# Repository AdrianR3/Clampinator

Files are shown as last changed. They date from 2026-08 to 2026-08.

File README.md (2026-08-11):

# The Clampinator

Inspired by the [ODrive Regen Clamp](https://shop.odriverobotics.com/products/odrive-regeneration-clamp), the clampinator is a custom built regeneration clamp targeting 16-60V systems.

PCB-front-red

## Key Features
 - 16-60V input
 - Adjustable clamp voltage via trimpot
 - Full reverse current protection via TI's [LM7481-Q1](https://www.ti.com/product/LM7481-Q1)
   - Ideal diode inrush current limiting supported, but marked as DNP
 - External pre-charge resistor
 - **FULL galvanic isolation between power and logic domains**
 - USB-C port for programming
 - STM32H5 based logic control
   - Digital control to disconnect power input from output
   - 2x CAN FD exposed w/toggleable termination resistors
 - Two onboard LEDs (Yellow and RGB)
 - Two 10k thermistor slots for thermistors
 - Two 15V outputs for active cooling fans

> [!CAUTION]
> The Clampinator must not be plugged in unless the power switch is off. To turn on, slide power switch to `PRECHARGE`, and only proceed to `RUN` after allowing at least 1s for the bulk capacitors to charge.

## Using the CAN bus

The STM32 on the board is equipped with two built in CAN FD controllers, and the Clampinator has two accompanying CAN transcievers in the bottom left of the board. There is dip switch `SW5` which can be used to toggle the internal 120Ω termination resistors.

## Building the Clampinator
The Clampinator can be ordered from sites like JLCPCB. The KiCAD source files are in `./KiCAD` and the production gerber files are in `./KiCAD/prod` along with the bom.

## Images 

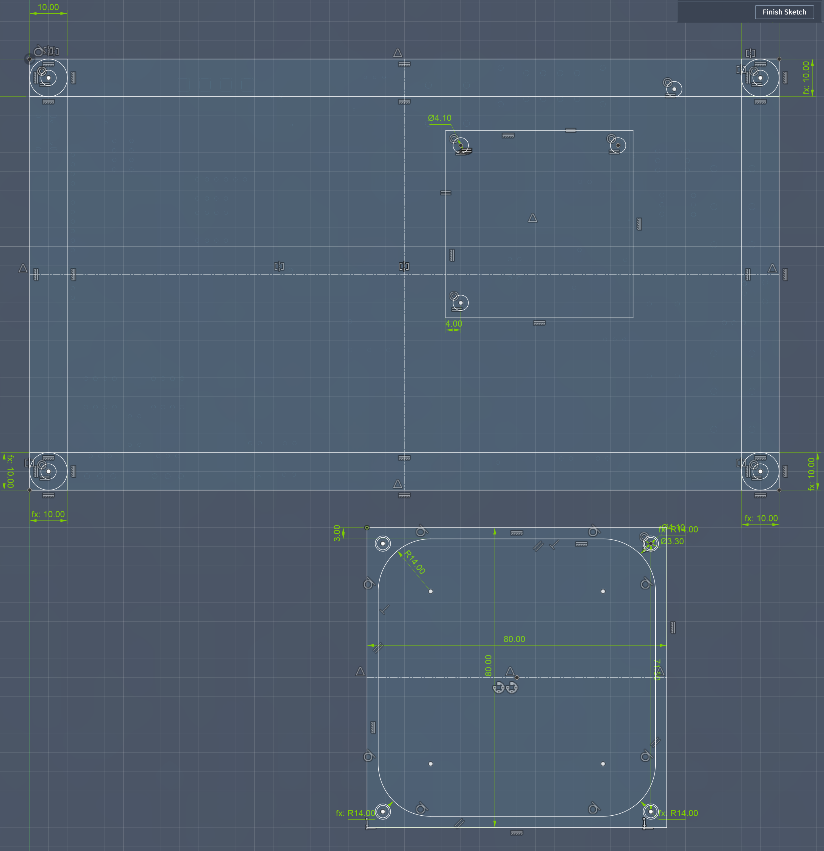
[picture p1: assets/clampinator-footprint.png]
Clampinator Base and Fan Footprint
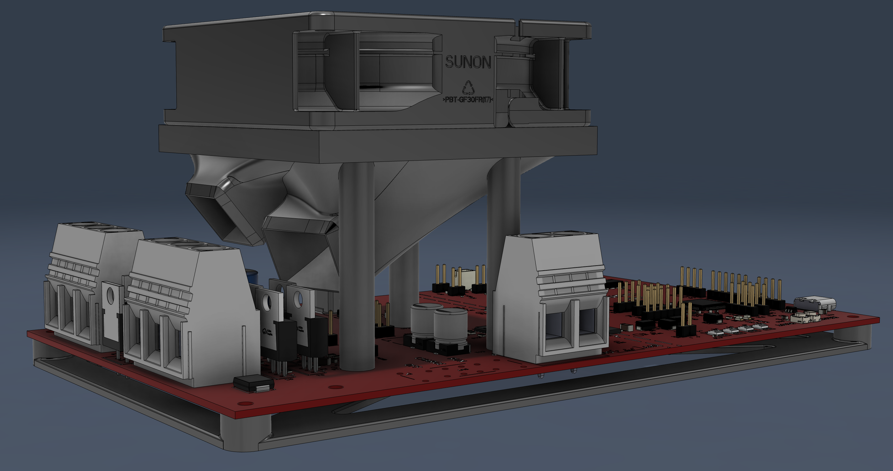
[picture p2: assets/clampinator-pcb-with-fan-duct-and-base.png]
Clampinator 3D Render with Fan and Duct
  
 
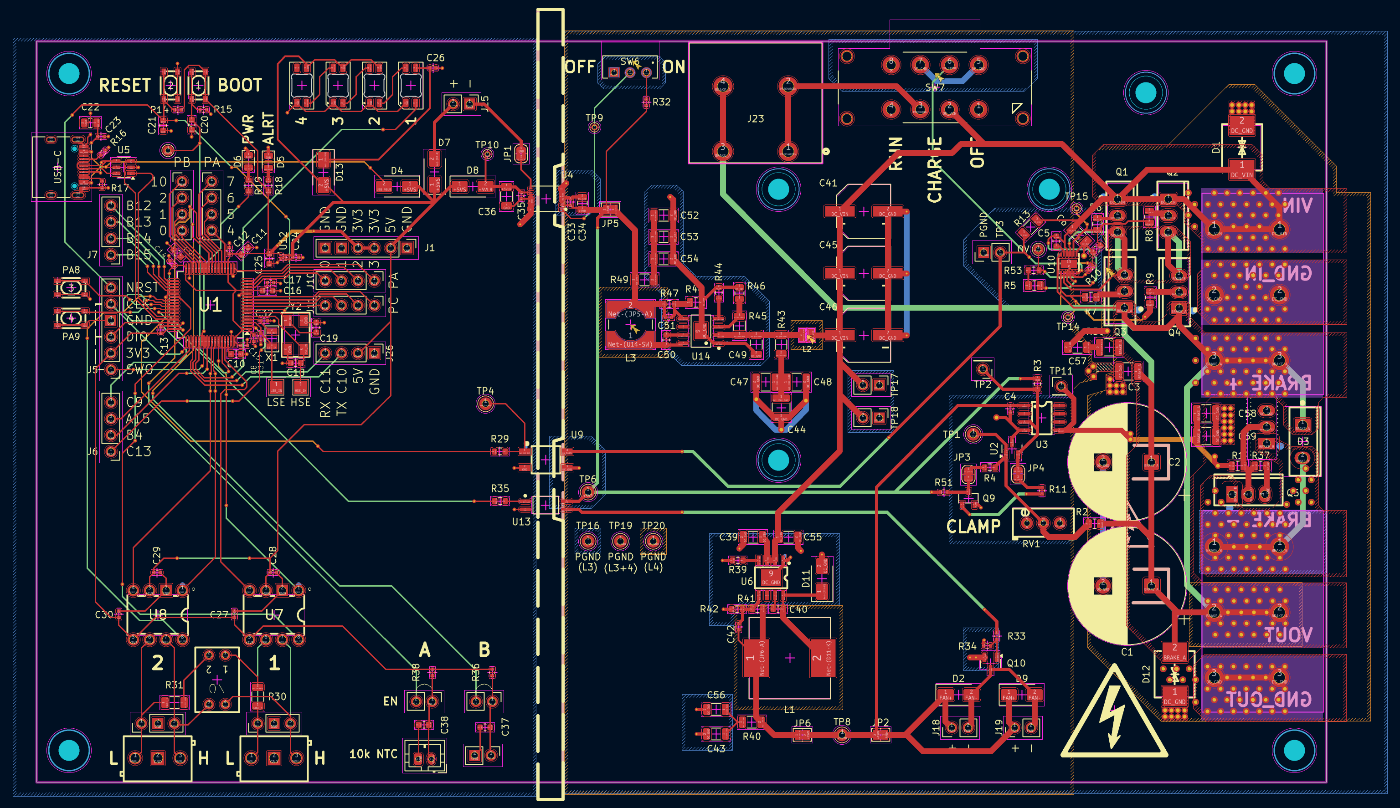
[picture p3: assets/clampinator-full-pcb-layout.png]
Clampinator Full PCB Layout
 

## Schematic

### Main Circuit
Main Circuit (Page 1 of 3)

## Logic Side Circuit
(Page 2 of 3)

## Thermal Management
(Page 3 of 3)

## BOM

| **Name** | **Purpose** | **Quantity** | **Total Cost (USD)** | **Link** | **Distributor** |
|---|---|---|---|---|---|
| LCSC Parts | Majority of PCB Components (With GSDL selected) | | 124.28 | | LCSC |
| 150R 25W Resistor | Precharge Resistor (Inrush Current Limiting) | 1 | 5.19 | https://www.digikey.com/en/products/detail/riedon-products-by-bourns/UAL25-150RF8/3886469 | DigiKey |
| 1818-VP036584000AG-ND | Connect Main Power | 2 | 5.50 | https://www.digikey.com/en/products/detail/amphenol-anytek/VP036584000AG/10378245 | DigiKey |
| 1818-VP0265840000G-ND | Connect Precharge Resistor | 1 | 3.10 | https://www.digikey.com/en/products/detail/amphenol-anytek/VP0265840000G/10378270 | DigiKey |
| EG1847-ND | Switch for Logic Side of Board | | 0.89 | https://www.digikey.com/en/products/detail/e-switch/EG1270/6076 | DigiKey |
| 259-1805-ND | Active Cooling Fan (price includes est. tariff) | 2 | 15.48 | https://www.digikey.com/en/products/detail/sunon-fans/MF80252V1-1000U-A99/6198743 | DigiKey |
| SW115-ND | (GPI-154-3013) Precharge Switch | | 1.83 | https://www.digikey.com/en/products/detail/cw-industries/GPI-154-3013/902 | DigiKey |
| 1.6R 500W Resistor | Main brake resistor | | 29.99 | https://www.youdaelectronics.com/products/1pc-500w-watt-16-ohm-500w-16r-aluminum-housing-wire-wound-resistor-29x52x250mm-3199 | Youda Electronics |
| JLCPCB + Stencil | Main Clampinator Board | 1 | 101.38 | | JLCPCB |

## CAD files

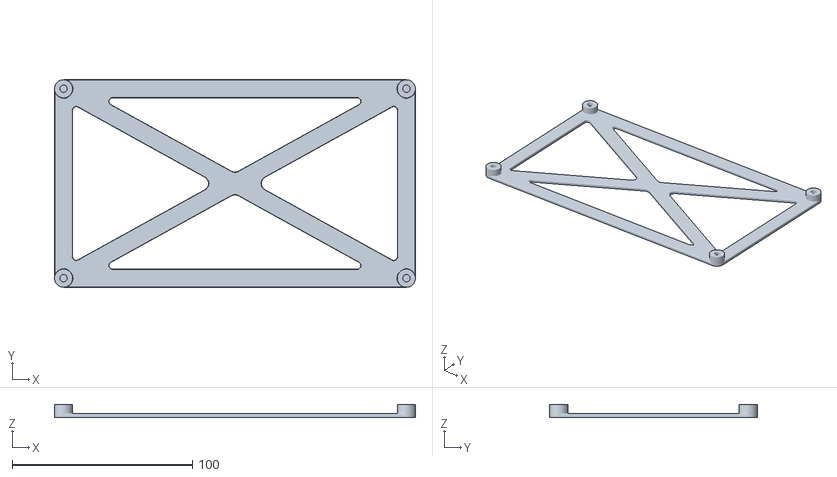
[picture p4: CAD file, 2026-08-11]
3dCAD/v1/Clampinator-base.stl
200.1 x 115.0 x 7.00

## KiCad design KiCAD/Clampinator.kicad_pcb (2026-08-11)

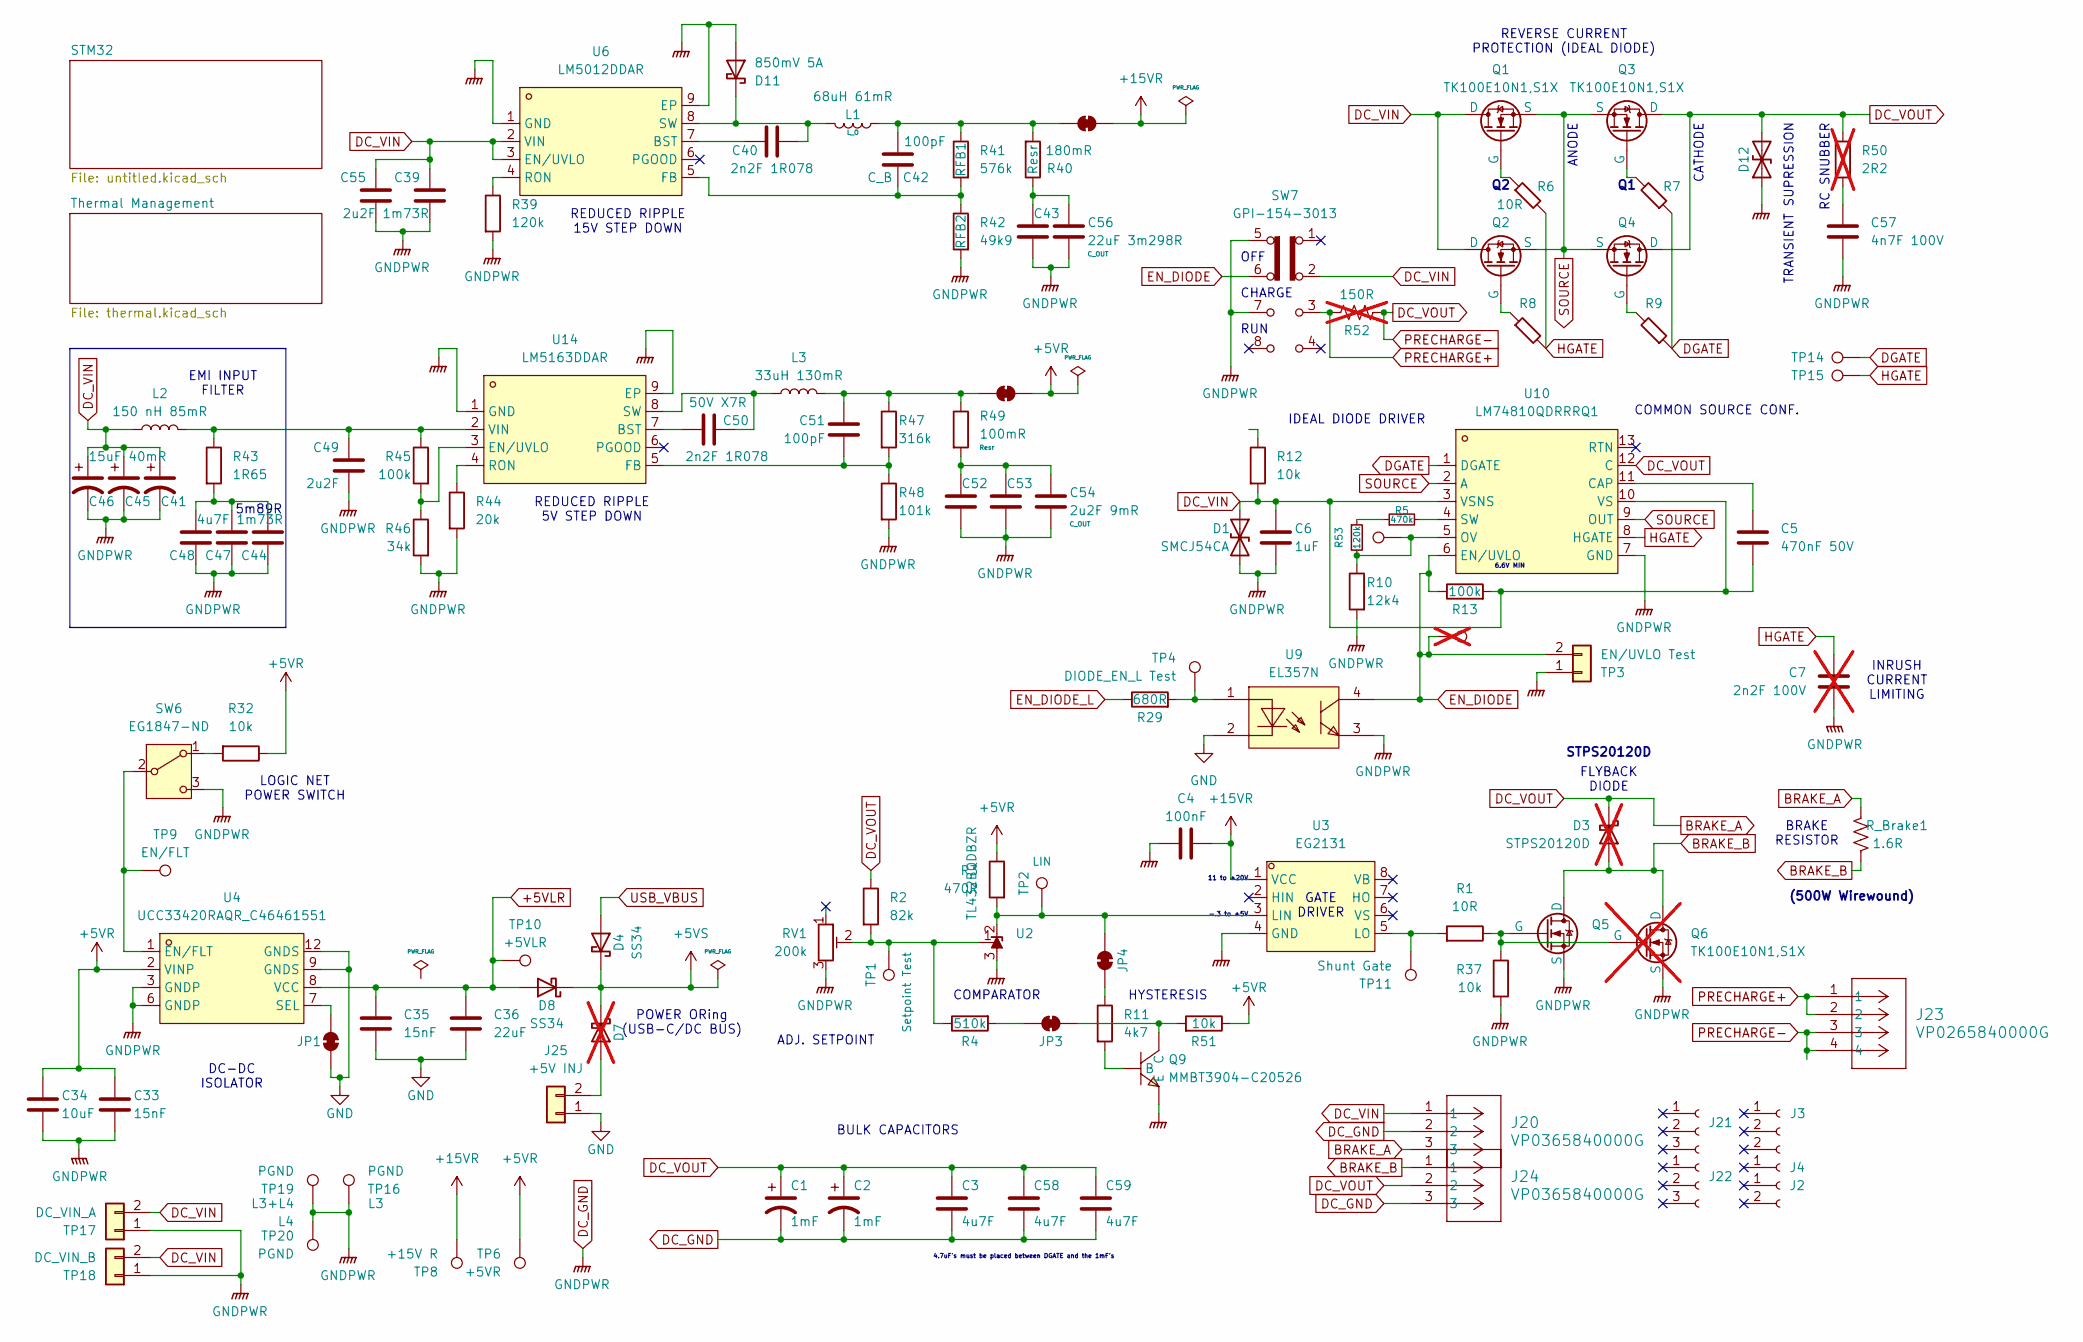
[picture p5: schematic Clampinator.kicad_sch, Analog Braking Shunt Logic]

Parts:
C1, C2: 1mF; CP_Radial_D18.0mm_P7.50mm; MPN ECA2AM102; LCSC Part C178408
C3, C58, C59: 4u7F; C_1210_3225Metric; LCSC Part C915836
C4: 100nF; C_0402_1005Metric; LCSC Part C307331
C5: 470nF 50V; C_0603_1608Metric; LCSC Part C1620
C6: 1uF; C_1206_3216Metric; LCSC Part C13832
C7: 2n2F 100V; C_0603_1608Metric; not fitted
C33, C35: 15nF; C_0402_1005Metric; LCSC Part C1548
C34: 10uF; C_0805_2012Metric; LCSC Part C15850
C36: 22uF; C_1206_3216Metric; LCSC Part C12891
C39, C55: 2u2F 1m73R; C_1206_3216Metric; LCSC Part C5122251
C40, C50: 2n2F 1R078; C_0603_1608Metric; LCSC Part C1604
C41, C45, C46: 15uF 40mR; CAP-SMD_BD8.0-L8.3-W8.3-LS9.3-FD; MPN 100SXV15M; LCSC Part C542593
C42, C51: 100pF; C_0402_1005Metric; LCSC Part C1546
C43, C56: 22uF 3m298R; C_1206_3216Metric; LCSC Part C12891
C44, C47, C48: 4u7F 1m73R; C_1210_3225Metric; LCSC Part C915836
C49: 2u2F; C_1206_3216Metric; LCSC Part C5122251
C52, C53, C54: 2u2F 9mR; C_1206_3216Metric; LCSC Part C5122251
C57: 4n7F 100V; C_1206_3216Metric; LCSC Part C393168
D1: SMCJ54CA; SMC_L6.9-W5.9-LS7.9-BI; MPN SMCJ54CA-13-F; LCSC Part C135179
D3: STPS20120D; TO-220AC_L10.0-W4.5-P5.08-T; MPN STPS20120D; LCSC Part C10623; not fitted
D4, D8: SS34; D_SMA; LCSC Part C8678
D7: SS34; D_SMA; LCSC Part C8678; not fitted
D11: 850mV 5A; D_SMA; LCSC Part C65010
D12: SMCJ64CA; SMC_L6.9-W5.9-LS7.9-BI; MPN SMCJ64CA/TR13; LCSC Part C123977
J2, J3, J4: Conn_01x02_Socket; PinHeader_1x02_P2.54mm_Vertical
J20, J24: VP0365840000G; VP0265840000G_THT; DigiKey BOM YES
J21, J22: Conn_01x03_Socket
J23: VP0265840000G; CONN04_VP026584_20P32X18P3_AMP; DigiKey BOM YES
J25: +5V INJ; PinHeader_1x02_P2.54mm_Vertical
JP1: SolderJumper_2_Bridged; SolderJumper-2_P1.3mm_Bridged2Bar_RoundedPad1.0x1.5mm
JP3, JP4: SolderJumper_2_Bridged; SolderJumper-2_P1.3mm_Bridged_RoundedPad1.0x1.5mm
JP5: SolderJumper_2_Bridged; SolderJumper-2_P1.3mm_Bridged2Bar_Pad1.0x1.5mm
JP6: +15VR; SolderJumper-2_P1.3mm_Bridged2Bar_Pad1.0x1.5mm
L1: 68uH 61mR; IND-SMD_L12.5-W12.5; MPN CYH125-68UH; LCSC Part C7431083
L2: 150 nH 85mR; WE-MAPI_2010; MPN 744383430033; LCSC Part C6069597
L3: 33uH 130mR; IND_SRR6038-330Y; MPN SRR6038-330Y; LCSC Part C2041395
Q1, Q2, Q3, Q4, Q5: TK100E10N1,S1X; TO-220-3_L10.0-W4.5-P2.54-L; MPN TK100E10N1,S1X; LCSC Part C5986394
Q6: TK100E10N1,S1X; TO-220-3_L10.0-W4.5-P2.54-L; MPN TK100E10N1,S1X; LCSC Part C5986394; not fitted
Q9: MMBT3904-C20526; SOT-23-3_L2.9-W1.3-P1.90-LS2.4-BR; MPN MMBT3904(RANGE:100-300); LCSC Part C20526
R1, R6, R7, R8, R9: 10R; R_0805_2012Metric; LCSC Part C17415
R2: 82k; R_0805_2012Metric; LCSC Part C2849357
R3: 470R; R_0603_1608Metric; LCSC Part C23179
R4: 510k; R_0603_1608Metric; LCSC Part C23192
R5: 470k; R_0805_2012Metric; LCSC Part C17709
R10: 12k4; R_0402_1005Metric; LCSC Part C25752
R11: 4k7; R_0402_1005Metric; LCSC Part C25900
R12: 10k; R_1206_3216Metric; LCSC Part C17902
R13, R45: 100k; R_1206_3216Metric; LCSC Part C17900
R29: 680R; R_0603_1608Metric; LCSC Part C23228
R32, R51: 10k; R_0402_1005Metric; LCSC Part C25744
R37: 10k; R_0805_2012Metric; LCSC Part C17414
R39, R53: 120k; R_0603_1608Metric; LCSC Part C25808
R40: 180mR; R_1206_3216Metric; LCSC Part C24436
R41: 576k; R_0603_1608Metric; LCSC Part C245981
R42: 49k9; R_0603_1608Metric; LCSC Part C23184
R43: 1R65; R_1206_3216Metric; LCSC Part C79297
R44: 20k; R_0603_1608Metric; LCSC Part C4184
R46: 34k; R_0805_2012Metric; LCSC Part C2077219
R47: 316k; R_0603_1608Metric; LCSC Part C185340
R48: 101k; R_0805_2012Metric; LCSC Part C7302896
R49: 100mR; R_1206_3216Metric; LCSC Part C25334
R50: 2R2; R_1210_3225Metric; MPN ERJ-P08J2R2V; not fitted
R52: 150R; SolderWire-4sqmm_1x02_P12mm_D3mm_OD6mm; MPN UAL25-150RF8; DigiKey BOM YES; not fitted
RV1: 200k; RES-ADJ-TH_3P-L9.5-W4.9-P2.50-L_3296W; MPN 3296W-1-204LF; LCSC Part C49190460
R_Brake1: 1.6R
SW6: EG1847-ND; SW_EG1270; DigiKey BOM YES
SW7: GPI-154-3013; SW_Slide_GPL-154-3013_DP3T_Angled; DigiKey BOM YES
TP1: Setpoint Test; TestPoint_THTPad_D2.0mm_Drill1.0mm
TP2: LIN; PinHeader_1x01_P2.54mm_Vertical
TP3: EN/UVLO Test; PinHeader_1x02_P2.54mm_Vertical
TP4: DIODE_EN_L Test; TestPoint_THTPad_D2.0mm_Drill1.0mm
TP6: +5VR; TestPoint_THTPad_D2.0mm_Drill1.0mm
TP8: +15V R; TestPoint_THTPad_D2.0mm_Drill1.0mm
TP9: EN/FLT; TestPoint_THTPad_D1.0mm_Drill0.5mm
TP10: +5VLR; TestPoint_THTPad_D1.0mm_Drill0.5mm
TP11: Shunt Gate; PinHeader_1x01_P2.54mm_Vertical
TP13: TestPoint; TestPoint_THTPad_D1.5mm_Drill0.7mm
TP14: D; TestPoint_THTPad_D1.0mm_Drill0.5mm
TP15: H; TestPoint_THTPad_D1.0mm_Drill0.5mm
TP16, TP19, TP20: PGND; TestPoint_THTPad_D2.0mm_Drill1.0mm
TP17: DC_VIN_A; PinHeader_1x02_P2.54mm_Vertical
TP18: DC_VIN_B; PinHeader_1x02_P2.54mm_Vertical
TP-not3: EN/UVLO Test; TestPoint_THTPad_D2.0mm_Drill1.0mm; not fitted
U2: TL432BQDBZR; SOT-23; LCSC Part C53724
U3: EG2131; SOIC-8_L5.0-W4.0-P1.27-LS6.0-BL; MPN EG2131; LCSC Part C193777
U4: UCC33420RAQR_C46461551; VSON-12_L5.0-W4.0-P0.65-TL_PUCC33420QRAQRQ1; MPN UCC33420RAQR; LCSC Part C46461551
U6: LM5012DDAR; SOPOWERPAD-8_L4.9-W3.9-P1.27-LS6.0-BL-EP; MPN LM5012DDAR; LCSC Part C6079494
U9: EL357N; OPTO-SMD-4_L4.4-W4.1-P2.54-LS7.0-TL; MPN EL357N(A)(TA)-G; LCSC Part C42385000
U10: LM74810QDRRRQ1; WSON-12_L3.0-W3.0-P0.50-TL-EP-2; MPN LM74810QDRRRQ1; LCSC Part C3215601
U14: LM5163DDAR; ESOP-8_L4.9-W3.9-P1.27-LS6.0-BL-EP2.6; MPN LM5163DDAR; LCSC Part C2873264

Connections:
+5VLR: C35.1, C36.1, D8.2 (A), TP10.1 (1_1), U4.8 (VCC)
+5VR: C33.1, C34.1, JP5.2 (B), R3.1, R32.1, R51.1, TP6.1 (1_1), U4.2 (VINP); also elsewhere on the board
+5VS: D4.1 (K), D7.1 (K), D8.1 (K); also elsewhere on the board
+15VR: C4.2, JP6.2 (B), TP8.1 (1_1), U3.1 (VCC); also elsewhere on the board
BRAKE_A: C1.1, C2.1, C3.1, C58.1, C59.1, D3.1 (K), D12.2 (A2), J20.3, J23.3, J23.4, J24.2, Q3.1 (D), Q4.1 (D), R2.1, R50.1, R52.2, R_Brake1.2, U10.12 (C)
BRAKE_B: D3.2 (A), J24.1, Q5.1 (D), Q6.1 (D), R_Brake1.1
DC_GND: C1.2, C2.2, C3.2, C4.1, C6.2, C7.2, C33.2, C34.2, C39.2, C41.2, C43.2, C44.2, C45.2, C46.2, C47.2, C48.2, C49.2, C52.2, C53.2, C54.2, C55.2, C56.2, C57.2, C58.2, C59.2, D1.2 (A2), D11.2 (A), D12.1 (A1), J20.2, J24.3, Q5.3 (S), Q6.3 (S), Q9.2 (E), R10.2, R37.2, R39.2, R42.2, R44.2, R46.2, R48.2, RV1.3, SW6.3 (C), SW7.5 (B), SW7.7 (C), TP3.1, TP16.1 (1_1), TP17.1, TP18.1, TP19.1 (1_1), TP20.1 (1_1), U2.3 (A), U3.4 (GND), U4.3 (GNDP), U4.6 (GNDP), U6.1 (GND), U6.9 (EP), U9.3 (EM), U10.7 (GND), U14.1 (GND), U14.9 (EP); also elsewhere on the board
DC_VIN: C5.2, C6.1, C39.1, C41.1, C45.1, C46.1, C55.1, D1.1 (A1), J20.1, L2.1, Q1.1 (D), Q2.1 (D), R12.2, R13.2, SW7.2 (B), TP17.2, TP18.2, U6.2 (VIN), U6.3 (EN/UVLO), U10.3 (VSNS), U10.10 (VS)
DGATE: R7.1, R9.1, TP14.1 (1_1), U10.1 (DGATE)
EN_DIODE: R13.1, SW7.6 (C), TP3.2, TP-not3.1, U9.4 (COL), U10.6 (EN/UVLO)
EN_DIODE_L: R29.1; also elsewhere on the board
GND: C35.2, C36.2, J25.1, JP1.1 (A), U4.9 (GNDS), U4.12 (GNDS), U9.2 (CA); also elsewhere on the board
HGATE: C7.1, R6.2, R8.2, TP15.1 (1_1), U10.8 (HGATE)
unnamed: C43.1, C56.1, R40.1
unnamed: C44.1, C47.1, C48.1, R43.2
unnamed: C52.1, C53.1, C54.1, R49.2
unnamed: C57.1, R50.2
unnamed: D7.2 (A), J25.2
unnamed: C40.2, D11.1 (K), L1.2, U6.8 (SW)
unnamed: JP1.2 (B), U4.7 (SEL)
unnamed: JP3.1 (A), R4.2
unnamed: JP3.2 (B), Q9.3 (C), R51.2
unnamed: JP4.1 (A), R3.2, TP2.1 (1_1), U2.2 (K), U3.3 (LIN)
unnamed: JP4.2 (B), R11.1
unnamed: C51.1, JP5.1 (A), L3.2, R47.1, R49.1
unnamed: C42.1, JP6.1 (A), L1.1, R40.2, R41.1
unnamed: Q1.2 (G), R6.1
unnamed: Q2.2 (G), R8.1
unnamed: Q3.2 (G), R7.2
unnamed: Q4.2 (G), R9.2
unnamed: Q5.2 (G), Q6.2 (G), R1.1, R37.1
unnamed: Q9.1 (B), R11.2
unnamed: R5.1, R53.1
unnamed: R32.2, SW6.1 (A)
unnamed: SW6.2 (B), TP9.1 (1_1), U4.1 (EN/FLT)
unnamed: R2.2, R4.1, RV1.2, TP1.1 (1_1), U2.1 (REF)
unnamed: R1.2, TP11.1 (1_1), U3.5 (LO)
unnamed: C40.1, U6.7 (BST)
unnamed: C42.2, R41.2, R42.1, U6.5 (FB)
unnamed: R39.1, U6.4 (RON)
unnamed: R29.2, TP4.1 (1_1), U9.1 (AN)
unnamed: C5.1, U10.11 (CAP)
unnamed: R10.1, R53.2, TP13.1 (1_1), U10.5 (OV)
unnamed: R5.2, U10.4 (SW)
unnamed: C50.2, U14.7 (BST)
unnamed: R45.2, R46.1, U14.3 (EN/UVLO)
unnamed: C51.2, R47.2, R48.1, U14.5 (FB)
unnamed: R44.1, U14.4 (RON)
unnamed: C50.1, L3.1, U14.8 (SW)
unnamed: C49.1, L2.2, R43.1, R45.1, U14.2 (VIN)
PRECHARGE+: J23.1, J23.2, R52.1, SW7.3 (C)
SOURCE: Q1.3 (S), Q2.3 (S), Q3.3 (S), Q4.3 (S), U10.2 (A), U10.9 (OUT)
USB_VBUS: D4.2 (A); also elsewhere on the board

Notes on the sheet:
ANODE
RC SNUBBER
HYSTERESIS
4.7uF's must be placed between DGATE and the 1mF's
COMMON SOURCE CONF.
GATE DRIVER
REVERSE CURRENT PROTECTION (IDEAL DIODE)
IDEAL DIODE DRIVER
DC-DC ISOLATOR
STPS20120D
FLYBACK DIODE
11 to +20V
CATHODE
CHARGE
6.6V MIN
EMI INPUT FILTER
RUN
LOGIC NET POWER SWITCH
-.3 to +5V
REDUCED RIPPLE 15V STEP DOWN
OFF
REDUCED RIPPLE 5V STEP DOWN
BULK CAPACITORS
(500W Wirewound)
BRAKE RESISTOR
COMPARATOR
INRUSH CURRENT LIMITING
TRANSIENT SUPRESSION
5m89R
ADJ. SETPOINT
POWER ORing (USB-C/DC BUS)

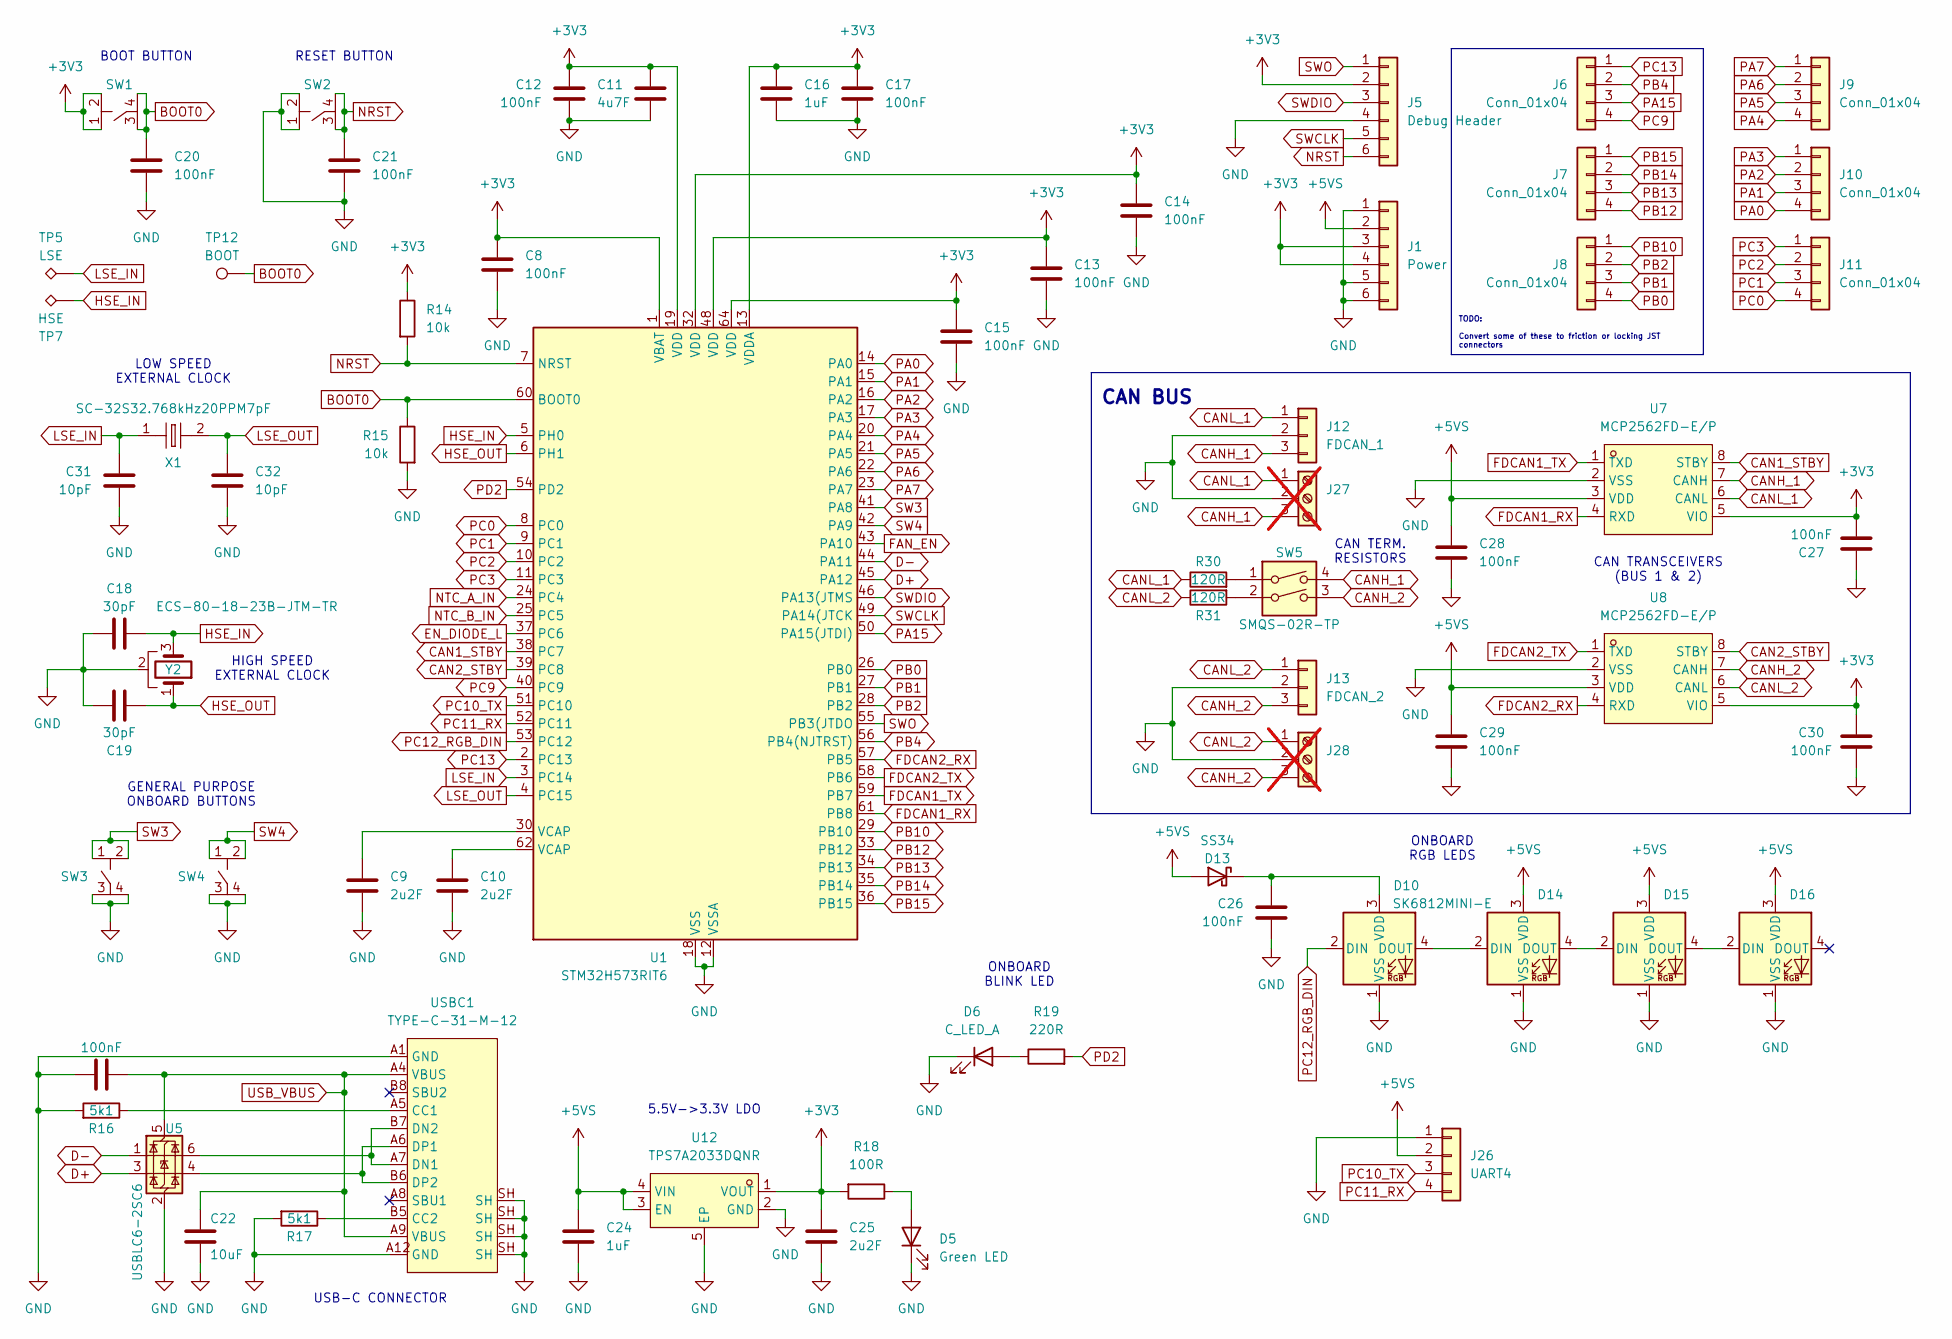
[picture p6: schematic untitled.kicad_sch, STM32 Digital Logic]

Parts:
C8, C12, C13, C14, C15, C17, C26, C27, C30: 100nF; C_0402_1005Metric; LCSC Part C1525
C9, C10, C25: 2u2F; C_0603_1608Metric; LCSC Part C23630
C11: 4u7F; C_0603_1608Metric; LCSC Part C19666
C16: 1uF; C_0603_1608Metric; LCSC Part C15849
C18, C19: 30pF; C_0603_1608Metric; LCSC Part C1658
C20, C21: 100nF; C_0603_1608Metric; LCSC Part C14663
C22: 10uF; C_0805_2012Metric; LCSC Part C440198
C23, C28, C29: 100nF; C_0402_1005Metric; LCSC Part C307331
C24: 1uF; C_0402_1005Metric; LCSC Part C52923
C31, C32: 10pF; C_0402_1005Metric; LCSC Part C32949
D5: Green LED; LED_0805_2012Metric; LCSC Part C2297
D6: C_LED_A; LED_0805_2012Metric; LCSC Part C2296
D10, D14, D15, D16: SK6812MINI-E; LED_SK6812MINI-E_3.2x2.8mm_P1.5mm
D13: SS34; D_SMA; LCSC Part C8678
J1: Power; PinHeader_1x06_P2.54mm_Vertical
J5: Debug Header; PinHeader_1x06_P2.54mm_Vertical
J6, J7, J8, J9, J10, J11: Conn_01x04; PinHeader_1x04_P2.54mm_Vertical
J12: FDCAN_1; PinHeader_1x03_P2.54mm_Vertical
J13: FDCAN_2; PinHeader_1x03_P2.54mm_Vertical
J26: UART4; PinHeader_1x04_P2.54mm_Vertical
J27, J28: Screw_Terminal_01x03; CONN-TH_3P-P3.50_OSTTE030161; not fitted
R14, R15: 10k; R_0402_1005Metric; LCSC Part C25744
R16, R17: 5k1; R_0402_1005Metric; LCSC Part C25905
R18: 100R; R_0603_1608Metric; LCSC Part C22775
R19: 220R; R_0603_1608Metric; LCSC Part C22962
R30, R31: 120R; R_1206_3216Metric; LCSC Part C17909
SW1, SW2, SW3, SW4: PTS810SJM250SMTRLFS; KEY-SMD_4P-L4.2-W3.2-P2.20-LS4.6; MPN PTS810SJM250SMTRLFS; LCSC Part C116501
SW5: SMQS-02R-TP; SW-TH_4P-L9.9-W6.8-P7.62-BL; MPN SMQS-02R-TP; LCSC Part C5299503
TP5: LSE; TestPoint_Pad_2.0x2.0mm
TP7: HSE; TestPoint_Pad_2.0x2.0mm
TP12: BOOT; TestPoint_THTPad_D1.5mm_Drill0.7mm
U1: STM32H573RIT6; LQFP-64_10x10mm_P0.5mm; LCSC Part C22371377
U5: USBLC6-2SC6; SOT-23-6; LCSC Part C7519
U7, U8: MCP2562FD-E/P; PDIP-8_L9.3-W6.4-P2.54-LS7.6-BL; MPN MCP2562FD-E/P; LCSC Part C640346
U12: TPS7A2033DQNR; UDFN-4_L1.0-W1.0-P0.65-TL; MPN TPS7A2033DQNR; LCSC Part C46459900
USBC1: TYPE-C-31-M-12; USB_C_Receptacle_HRO_TYPE-C-31-M-12; MPN TYPE-C-31-M-12; LCSC Part C165948
X1: SC-32S32.768kHz20PPM7pF; OSC-SMD_L3.2-W1.5; MPN SC-32S32.768kHz20PPM7pF; LCSC Part C97604
Y2: ECS-80-18-23B-JTM-TR; CRYSTAL-SMD_4P-L6.0-W3.5-BL; MPN ECS-80-18-23B-JTM-TR; LCSC Part C2450633

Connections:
+3V3: C8.1, C11.1, C12.1, C13.1, C14.1, C15.1, C16.1, C17.1, C25.1, C27.1, C30.1, J1.3, J1.4, J5.2, R14.1, R18.2, SW1.1, SW1.2, U1.1 (VBAT), U1.13 (VDDA), U1.19 (VDD), U1.32 (VDD), U1.48 (VDD), U1.64 (VDD), U7.5 (VIO), U8.5 (VIO), U12.1 (VOUT); also elsewhere on the board
+5VS: C24.1, C28.1, C29.2, D13.2 (A), D14.3 (VDD), D15.3 (VDD), D16.3 (VDD), J1.2, J26.2, U7.3 (VDD), U8.3 (VDD), U12.3 (EN), U12.4 (VIN); also elsewhere on the board
BOOT0: C20.1, R15.1, SW1.3, SW1.4, TP12.1 (1_1), U1.60 (BOOT0)
CAN1_STBY: U1.38 (PC7), U7.8 (STBY)
CAN2_STBY: U1.39 (PC8), U8.8 (STBY)
CANH_1: J12.3, J27.3, SW5.4, U7.7 (CANH)
CANH_2: J13.3, J28.3, SW5.3, U8.7 (CANH)
CANL_1: J12.1, J27.1, R30.1, U7.6 (CANL)
CANL_2: J13.1, J28.1, R31.1, U8.6 (CANL)
D+: U1.45 (PA12), U5.3 (I/O2)
D-: U1.44 (PA11), U5.1 (I/O1)
EN_DIODE_L: U1.37 (PC6); also elsewhere on the board
FAN_EN: U1.43 (PA10); also elsewhere on the board
FDCAN1_RX: U1.61 (PB8), U7.4 (RXD)
FDCAN1_TX: U1.59 (PB7), U7.1 (TXD)
FDCAN2_RX: U1.57 (PB5), U8.4 (RXD)
FDCAN2_TX: U1.58 (PB6), U8.1 (TXD)
GND: C8.2, C9.2, C10.2, C11.2, C12.2, C13.2, C14.2, C15.2, C16.2, C17.2, C18.1, C19.2, C20.2, C21.2, C22.2, C23.2, C24.2, C25.2, C26.2, C27.2, C28.2, C29.1, C30.2, C31.2, C32.2, D5.1 (K), D6.1 (K), D10.1 (VSS), D14.1 (VSS), D15.1 (VSS), D16.1 (VSS), J1.1, J1.5, J1.6, J5.4, J12.2, J13.2, J26.1, J27.2, J28.2, R15.2, R16.2, R17.2, SW2.1, SW2.2, SW3.3, SW3.4, SW4.3, SW4.4, U1.12 (VSSA), U1.18 (VSS), U1.31 (VSS), U1.47 (VSS), U1.63 (VSS), U5.2 (GND), U7.2 (VSS), U8.2 (VSS), U12.2 (GND), U12.5 (EP), USBC1.A1 (GND), USBC1.A12 (GND), USBC1.B1 (GND), USBC1.B12 (GND), USBC1.SH, Y2.2, Y2.4; also elsewhere on the board
HSE_IN: C18.2, TP7.1 (1_1), U1.5 (PH0), Y2.3
HSE_OUT: C19.1, U1.6 (PH1), Y2.1
LSE_IN: C31.1, TP5.1 (1_1), U1.3 (PC14), X1.1
LSE_OUT: C32.1, U1.4 (PC15), X1.2
NRST: C21.1, J5.6, R14.2, SW2.3, SW2.4, U1.7 (NRST)
NTC_A_IN: U1.24 (PC4); also elsewhere on the board
NTC_B_IN: U1.25 (PC5); also elsewhere on the board
unnamed: C9.1, U1.30 (VCAP)
unnamed: C10.1, U1.62 (VCAP)
unnamed: D5.2 (A), R18.1
unnamed: D6.2 (A), R19.1
unnamed: D10.4 (DOUT), D14.2 (DIN)
unnamed: C26.1, D10.3 (VDD), D13.1 (K)
unnamed: D14.4 (DOUT), D15.2 (DIN)
unnamed: D15.4 (DOUT), D16.2 (DIN)
unnamed: R30.2, SW5.1
unnamed: R31.2, SW5.2
unnamed: R16.1, USBC1.A5 (CC1)
unnamed: R17.1, USBC1.B5 (CC2)
unnamed: U5.6 (I/O1), USBC1.A7 (DN1), USBC1.B7 (DN2)
unnamed: U5.4 (I/O2), USBC1.A6 (DP1), USBC1.B6 (DP2)
PA0: J10.4, U1.14 (PA0)
PA1: J10.3, U1.15 (PA1)
PA2: J10.2, U1.16 (PA2)
PA3: J10.1, U1.17 (PA3)
PA4: J9.4, U1.20 (PA4)
PA5: J9.3, U1.21 (PA5)
PA6: J9.2, U1.22 (PA6)
PA7: J9.1, U1.23 (PA7)
PA15: J6.3, U1.50 (PA15(JTDI))
PB0: J8.4, U1.26 (PB0)
PB1: J8.3, U1.27 (PB1)
PB2: J8.2, U1.28 (PB2)
PB4: J6.2, U1.56 (PB4(NJTRST))
PB10: J8.1, U1.29 (PB10)
PB12: J7.4, U1.33 (PB12)
PB13: J7.3, U1.34 (PB13)
PB14: J7.2, U1.35 (PB14)
PB15: J7.1, U1.36 (PB15)
PC0: J11.4, U1.8 (PC0)
PC1: J11.3, U1.9 (PC1)
PC2: J11.2, U1.10 (PC2)
PC3: J11.1, U1.11 (PC3)
PC9: J6.4, U1.40 (PC9)
PC10_TX: J26.3, U1.51 (PC10)
PC11_RX: J26.4, U1.52 (PC11)
PC12_RGB_DIN: D10.2 (DIN), U1.53 (PC12)
PC13: J6.1, U1.2 (PC13)
PD2: R19.2, U1.54 (PD2)
SW3: SW3.1, SW3.2, U1.41 (PA8)
SW4: SW4.1, SW4.2, U1.42 (PA9)
SWCLK: J5.5, U1.49 (PA14(JTCK)
SWDIO: J5.3, U1.46 (PA13(JTMS)
SWO: J5.1, U1.55 (PB3(JTDO)
USB_VBUS: C22.1, C23.1, U5.5 (VBUS), USBC1.A4 (VBUS), USBC1.A9 (VBUS), USBC1.B4 (VBUS), USBC1.B9 (VBUS); also elsewhere on the board

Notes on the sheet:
CAN BUS
ONBOARD RGB LEDS
USB-C CONNECTOR
LOW SPEED EXTERNAL CLOCK
CAN TRANSCEIVERS (BUS 1 & 2)
HIGH SPEED EXTERNAL CLOCK
BOOT BUTTON
ONBOARD BLINK LED
CAN TERM. RESISTORS
RESET BUTTON
5.5V->3.3V LDO
GENERAL PURPOSE ONBOARD BUTTONS
TODO: Convert some of these to friction or locking JST connectors

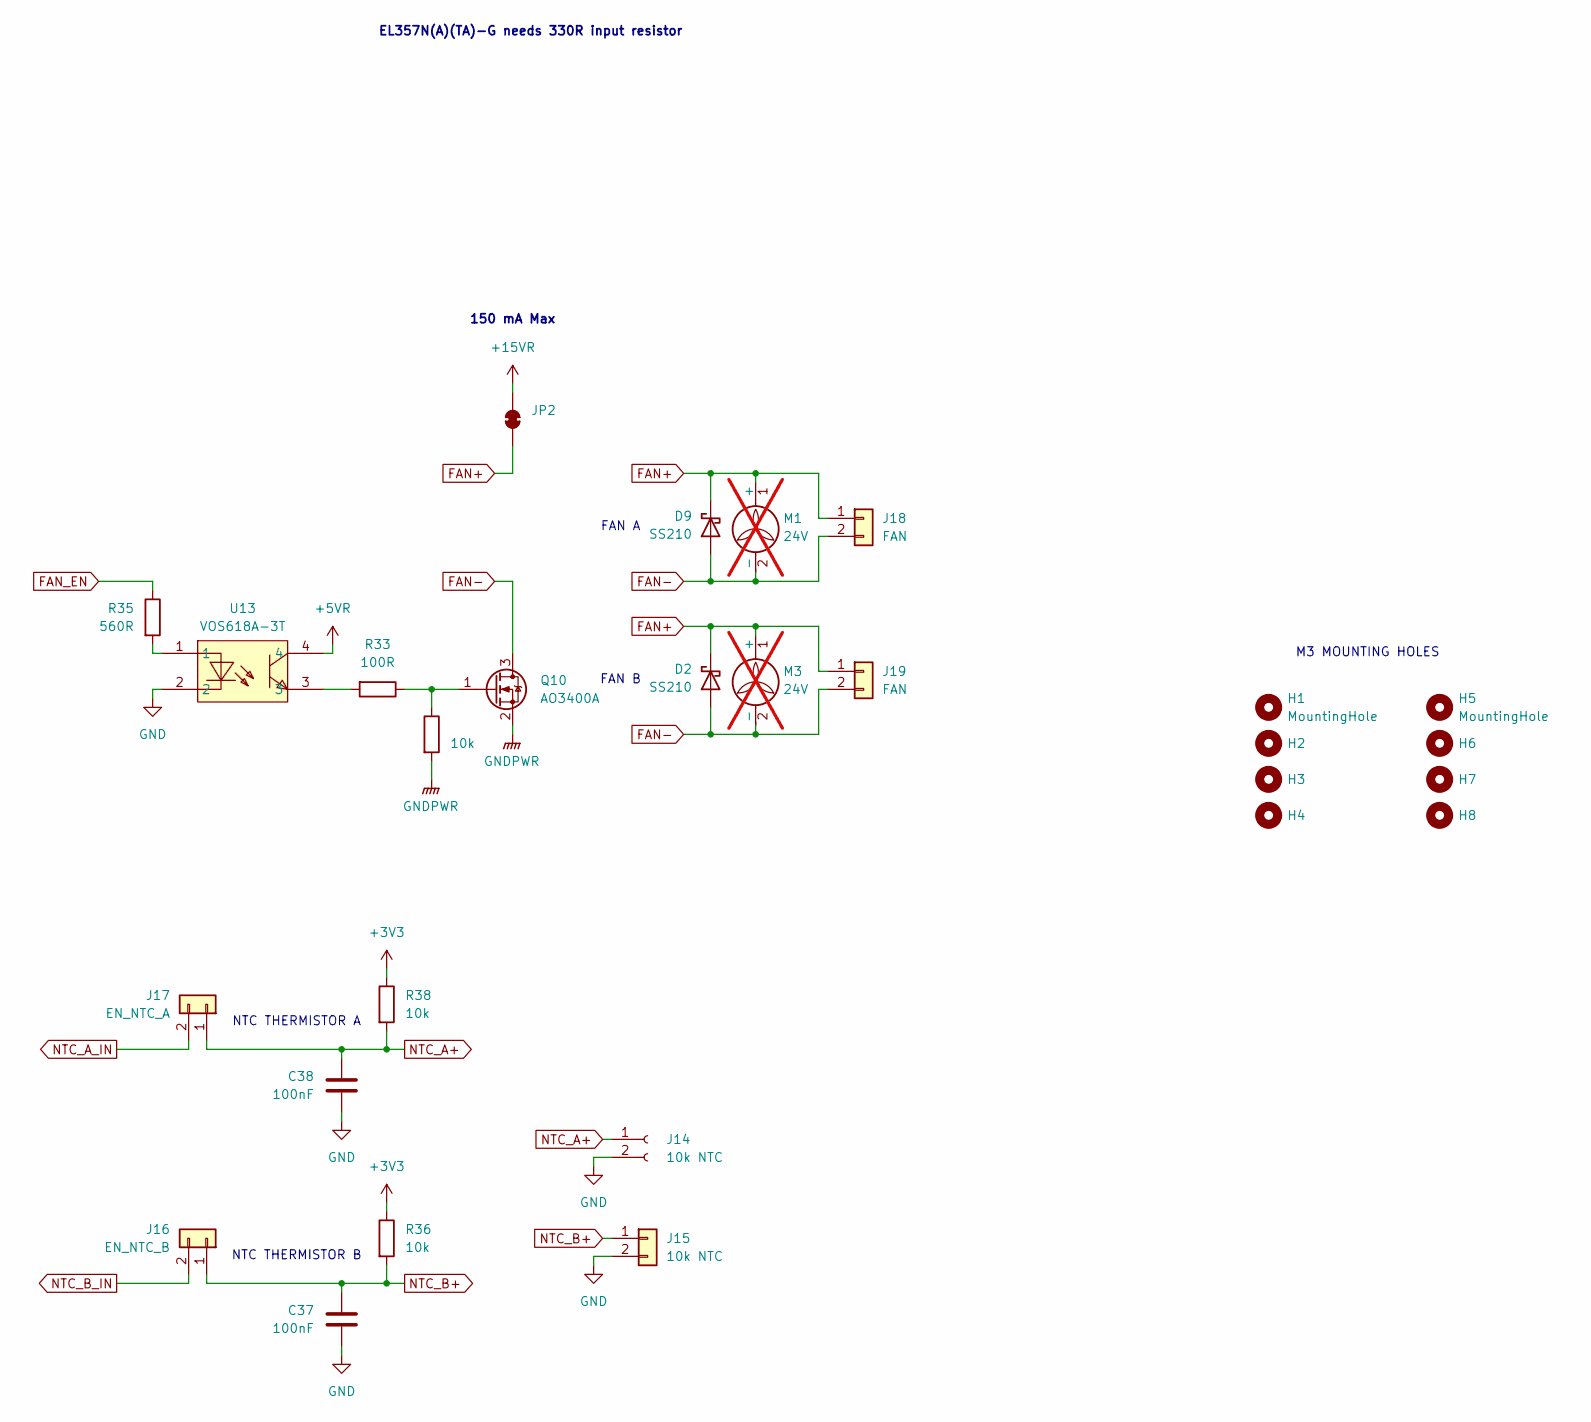
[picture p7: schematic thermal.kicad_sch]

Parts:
C37, C38: 100nF; C_0603_1608Metric; LCSC Part C14663
D2, D9: SS210; D_SMA; LCSC Part C14996
H1, H2, H3, H4, H5, H6, H7, H8: MountingHole; MountingHole_3.2mm_M3
J14: 10k NTC; JST_PH_B2B-PH-K_1x02_P2.00mm_Vertical
J15: 10k NTC; PinHeader_1x02_P2.54mm_Vertical
J16: EN_NTC_B; PinHeader_1x02_P2.54mm_Vertical
J17: EN_NTC_A; PinHeader_1x02_P2.54mm_Vertical
J18, J19: FAN; PinHeader_1x02_P2.54mm_Vertical
JP2: SolderJumper_2_Bridged; SolderJumper-2_P1.3mm_Bridged2Bar_Pad1.0x1.5mm
M1, M3: 24V; MPN MF80252V1-1000U-A99; DigiKey BOM YES; not fitted
Q10: AO3400A; SOT-23; LCSC Part C20917
R33: 100R; R_0402_1005Metric; LCSC Part C25076
R34, R36, R38: 10k; R_0402_1005Metric; LCSC Part C25744
R35: 560R; R_0603_1608Metric; LCSC Part C23204
U13: VOS618A-3T; SOP-4_L4.4-W2.6-P1.27-LS7.0-BL; MPN VOS618A-3T; LCSC Part C17494890

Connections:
+3V3: R36.1, R38.1; also elsewhere on the board
+5VR: U13.4; also elsewhere on the board
+15VR: JP2.2 (B); also elsewhere on the board
DC_GND: Q10.2 (S), R34.2; also elsewhere on the board
FAN+: D2.1 (K), D9.1 (K), J18.1, J19.1, JP2.1 (A), M1.1 (+), M3.1 (+)
FAN-: D2.2 (A), D9.2 (A), J18.2, J19.2, M1.2 (-), M3.2 (-), Q10.3 (D)
FAN_EN: R35.1; also elsewhere on the board
GND: C37.2, C38.2, J14.2, J15.2, U13.2; also elsewhere on the board
NTC_A+: C38.1, J14.1, J17.1, R38.2
NTC_A_IN: J17.2; also elsewhere on the board
NTC_B+: C37.1, J15.1, J16.1, R36.2
NTC_B_IN: J16.2; also elsewhere on the board
unnamed: Q10.1 (G), R33.1, R34.1
unnamed: R33.2, U13.3
unnamed: R35.2, U13.1

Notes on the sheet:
150 mA Max
M3 MOUNTING HOLES
FAN A
NTC THERMISTOR B
NTC THERMISTOR A
FAN B
EL357N(A)(TA)-G needs 330R input resistor

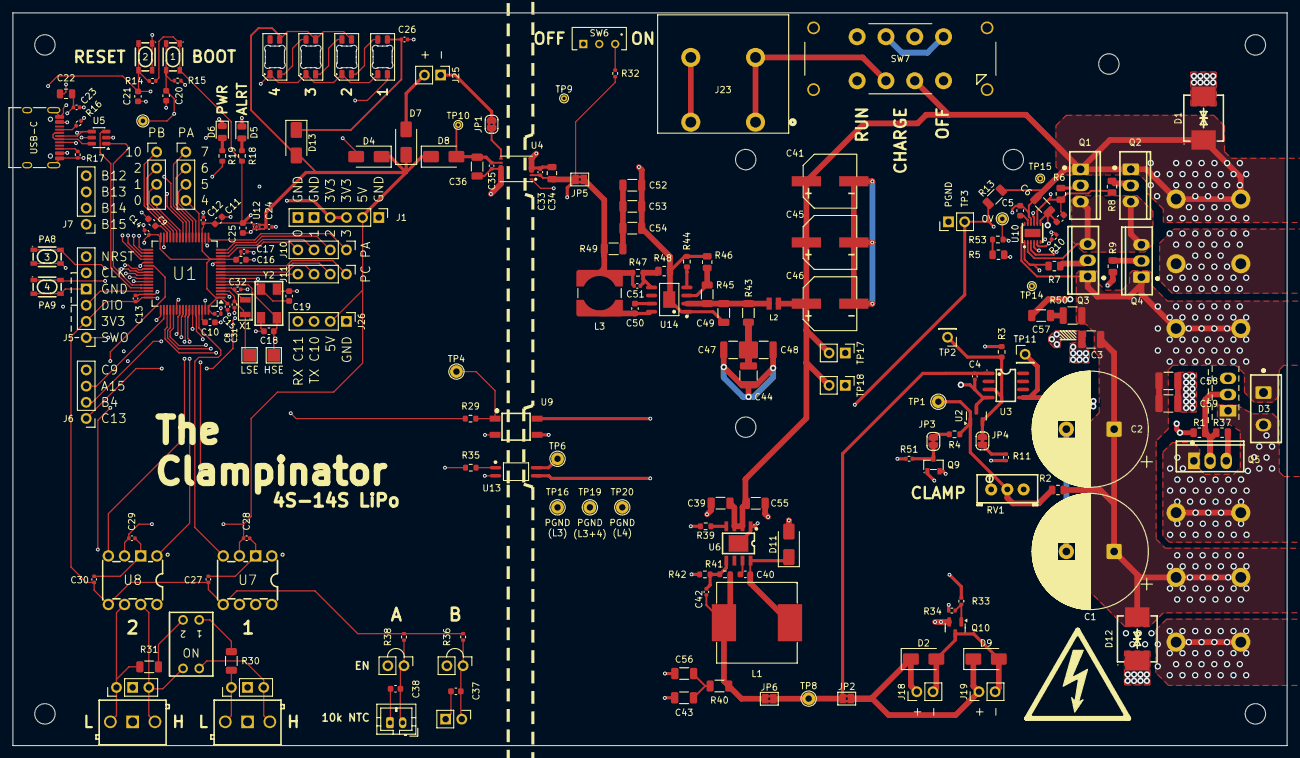
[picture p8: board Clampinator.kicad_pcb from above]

Board: 4 copper layers, 200.0 x 115.0 mm, 209 parts (0 on the bottom side), 129 nets.

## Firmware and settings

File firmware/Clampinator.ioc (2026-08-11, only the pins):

Mcu.UserName=STM32H573RITx
PA11.Signal=USB_DM
PA12.Signal=USB_DP
PA13(JTMS/SWDIO).Signal=DEBUG_JTMS-SWDIO
PA14(JTCK/SWCLK).Signal=DEBUG_JTCK-SWCLK
PB5.Signal=FDCAN2_RX
PB6.Signal=FDCAN2_TX
PB7.Signal=FDCAN1_TX
PB8.Signal=FDCAN1_RX
PC14-OSC32_IN(OSC32_IN).Signal=RCC_OSC32_IN
PC15-OSC32_OUT(OSC32_OUT).Signal=RCC_OSC32_OUT
PC4.Signal=ADCx_INP4
PC5.Signal=ADCx_INP8
PH0-OSC_IN(PH0).Signal=RCC_OSC_IN
PH1-OSC_OUT(PH1).Signal=RCC_OSC_OUT

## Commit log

2026-07-01 Upload v0.1
    [Clampinator.kicad_pcb, Clampinator.kicad_sch, thermal.kicad_sch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]
2026-08-04 Sync KiCAD project
    Forgot to push this earlier
    [Clampinator.kicad_pcb, Clampinator.kicad_sch, thermal.kicad_sch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]
2026-08-04 Fix all DRC errors
    [Clampinator.kicad_pcb, Clampinator.kicad_sch, thermal.kicad_sch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]
2026-08-04 Moved most of silkscreens into readable areas, moved some footprints for hand-soldering
    [Clampinator.kicad_pcb]
2026-08-04 Labels, silkscreens, shifted footprints
    [Clampinator.kicad_pcb]
2026-08-04 Add full stack GND fills, adjust thermal spoke widths, silkscreen clearance/other DRC warning fixes
    [Clampinator.kicad_pcb]
2026-08-06 Oscillator Test Pads + Re-Fix USB-C
    [Clampinator.kicad_pcb, Clampinator.kicad_sch, untitled.kicad_sch]
2026-08-06 USB-C Schematic Changes
    [untitled.kicad_sch]
2026-08-06 Shrunk edge cuts, Started fixing GND fills, Changed pad shapes, Nudged footprints around
    [Clampinator.kicad_pcb, Clampinator.kicad_sch]
2026-08-06 L3 and L4 Power GND Keep Outs, Shifting Footprints
    [Clampinator.kicad_pcb]
2026-08-06 Add M3 mounting holes, Fix DRC Errors, Merge L3 Quiet Power GND Fills
    [Clampinator.kicad_pcb, thermal.kicad_sch]
2026-08-07 Change some TPs to 2.54mm pin headers, silkscreen changes, start led redo
    [Clampinator.kicad_pcb, Clampinator.kicad_sch, untitled.kicad_sch]
2026-08-09 Replace RGB LED with cheaper SK6812 LEDs, expose freed UART pins
    [Clampinator.kicad_pcb, untitled.kicad_sch]
2026-08-09 Fixed silly miswired CAN transceivers
    [Clampinator.kicad_pcb, thermal.kicad_sch, untitled.kicad_sch]
2026-08-09 Finish SK7812 layouts + new forward mount footprint from reverse extended leads footprint
    [Clampinator.kicad_pcb, untitled.kicad_sch]
2026-08-09 Clean up traces
    [Clampinator.kicad_pcb]
2026-08-09 Resolve DRC errors, cleanup traces, nudge footprints for hand soldering
    [Clampinator.kicad_pcb, untitled.kicad_sch]
2026-08-09 Added pin silkscreen labels, nudged existing labels for readability
    Most of the pin labels say `PWR` for now
    [Clampinator.kicad_pcb]
2026-08-09 Fill in labels and align capacitors
    [Clampinator.kicad_pcb]
2026-08-10 Swap out input TVS for 14S maximum, relinked easyeda2kicad library, added extra shunting NMOS (DNP-ed)
    [Clampinator.kicad_pcb, Clampinator.kicad_sch, thermal.kicad_sch]
2026-08-10 Fixed footprint libraries, corrected terminal block footprints, added 3d model for precharge resistor terminal block
    [Clampinator.kicad_pcb, Clampinator.kicad_sch, untitled.kicad_sch]
2026-08-10 Fix 3P Terminal and USB-C Models, change silkscreen preview color to red
    [Clampinator.kicad_pcb, Clampinator.kicad_sch]
2026-08-10 Play around with warning text, resolved most types of DRC warnings
    [Clampinator.kicad_pcb]
2026-08-10 Extra PGND test pads for ground noise/bounce testing
    [Clampinator.kicad_pcb, Clampinator.kicad_sch]
2026-08-10 Add exposed solder pads (F.Mask) and hexagonal stitching vias
    [Clampinator.kicad_pcb]
2026-08-10 Resolved majority of remaining DRC warnings (+ignored library copy similarity check)
    [Clampinator.kicad_pcb]
2026-08-11 Cleanup copper fills
    [Clampinator.kicad_pcb]
2026-08-11 Add board name in silkscreen, hide incorrect 3d model for slide switch
    [Clampinator.kicad_pcb]
2026-08-11 Fix again recurring capacitor footprint overlap
    [Clampinator.kicad_pcb]
2026-08-11 Inital production files for v1
    [Clampinator.kicad_pcb]
2026-08-11 Create fan duct and mounting frame (for zipties)
    [Clampinator-base.stl]
2026-08-11 Initial firmware from STM32CubeMX
2026-08-11 Move PCB cad model
2026-08-11 Add short-BOM csv and to README
    [short-bom-v1.csv]

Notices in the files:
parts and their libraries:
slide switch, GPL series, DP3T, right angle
